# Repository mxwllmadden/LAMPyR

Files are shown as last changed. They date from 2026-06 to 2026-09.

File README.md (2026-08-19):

# LAMPyR

LAMPyR is a Python framework for running and managing behavioral experiment rigs. It provides a command-line interface and a Textual terminal UI for configuring rig hardware/interfaces, tracking mouse performance, running automated behavioral training paradigms, and has a notification manager to alert experimenters to session completion.

## Features

- Click-based `lampyr` command-line interface
- Textual TUI launcher (`lampyr go`)
- Rig configuration and calibration helpers
- Mouse creation, retirement, paradigm assignment, and run history
- Session and mouse data persistence using JSON/HDF5-backed utilities
- Optional Pushover notifications
- Hardware build files in `hardware/`
- Arduino firmware sketches for Bandit rig variants in `firmware/`

## Documentation

- [CLI command reference](docs/cli_commands.md)
- [GUI workflow](docs/gui_workflow.md)
- [Application architecture and segment inheritance](docs/app_architecture_and_segments.md)
- [Training management](docs/training_management.md)

## Requirements

- Windows is recommended for hardware/TUI operation; some rig and touch-overlay features are Windows-specific.
- Linux is supported for CLI operation with a Linux compatible TUI planned soon.
- Conda or Miniforge/Miniconda
- Python 3.10 or newer; the provided Conda environment uses Python 3.12
- Git, if installing directly from GitHub
- Arduino drivers/firmware as required by your rig hardware

## Installation

### Recommended: Conda environment from this repository

From the repository root:

```bat
conda env create -f lampyr.yaml
conda activate lampyr
pip install .
```

Verify the install:

```bat
lampyr --help
lampyr info
```

### Developer install

Use an editable install if you plan to modify the source code:

```bat
conda env create -f lampyr.yaml
conda activate lampyr
pip install -e .
```

### Install directly from GitHub

```bat
conda create -n lampyr python=3.12 -y
conda activate lampyr
conda install -c conda-forge git -y
pip install "git+https://github.com/HudaLaboratory/LAMPyR.git@main"
```

### Optional video support

If you install without the provided Conda environment and need OpenCV/video support:

```bat
pip install "lampyr[video]"
```

For a local checkout, use:

```bat
pip install ".[video]"
```

## Windows setup scripts

This repository includes batch files for convenience:

- `lampyr_setup.bat` - installs/refreshes a LAMPyR Conda environment from the GitHub `main` branch.
- `lampyr_update.bat` - updates dependencies and reinstalls LAMPyR from GitHub.

Review these scripts before running them, especially on machines with existing Conda environments.

## Configuration

LAMPyR stores user configuration under:

```text
%LOCALAPPDATA%\lampyr\config.json
```

Default settings include a shared mouse data directory:

```text
N:/SHARED/Maxwell_LAMPyR_MouseData
```

On first run, configure the installation (every other command requires this):

```bat
lampyr configure
```

Then inspect and configure the installation:

```bat
lampyr info
lampyr rig info
lampyr rig configure
lampyr rig calibrate
```

To reset configuration to defaults:

```bat
lampyr reset
```

> Note: `lampyr reset` is currently non-functional (`reset_to_default()` is
> not yet implemented) and will raise an error.

## Basic usage

Launch the terminal UI:

```bat
lampyr go
```

List available behaviors:

```bat
lampyr list
```

Create and inspect a mouse:

```bat
lampyr mouse create MOUSE_ID
lampyr mouse info MOUSE_ID
lampyr mouse list
```

Set or inspect a mouse paradigm/stage:

```bat
lampyr mouse paradigm MOUSE_ID
lampyr mouse paradigm MOUSE_ID BanditParadigm3
lampyr mouse paradigm MOUSE_ID BanditParadigm3 --stage Stage1AnyWheel
```

Run a behavior for a mouse:

```bat
lampyr mouse run MOUSE_ID
lampyr mouse run MOUSE_ID BEHAVIOR_NAME
```

Run a behavior directly:

```bat
lampyr run BEHAVIOR_NAME
```

Common stop-condition options include:

```text
--duration_limit / -dl
--trial_limit / -tl
--reward_limit / -rl
--merit_limit / -ml
--demerit_limit / -dml
```

Use command help for the full option list:

```bat
lampyr mouse run --help
lampyr run --help
```

## Notifications

LAMPyR supports Pushover notifications. Configure an app token and users with:

```bat
lampyr user set-token TOKEN
lampyr user create USERNAME --pushover_user_key USER_KEY
lampyr user list
lampyr user ping --user USERNAME --message "LAMPyR notification test"
```

## Hardware build files

Hardware files for building LAMPyR rigs are in `hardware/`:

- `hardware/BOM_Hardware.xlsx` - hardware bill of materials.
- `hardware/3d models/` - printable 3D model files.
- `hardware/Custom PCB shield/` - PCB shield fabrication files, BOM, designators, and pick-and-place positions.
- `hardware/eMachineShop design files/` - eMachineShop design files for machined components.

## Firmware

Arduino sketches for supported rig variants are in `firmware/`. Flash the sketch matching your rig hardware before attempting to run sessions.

## Project layout

```text
lampyr/                 Python package
lampyr/interfaces/      CLI (click_cli) and Textual TUI (textual_tui) entry points
lampyr/managers/        Data, mouse, rig, plugin, and notification managers
lampyr/rigs/            Hardware rig abstractions and Bandit rig components
lampyr/segments/        Segment, task, trial, stage, and paradigm abstractions
lampyr/behaviors/       Behavior implementations
lampyr/analysis/        Data analysis helpers
lampyr/main.py, config.py, primatives.py, files.py, actions.py, math.py, version.py   Core runtime modules
hardware/               Hardware BOM, 3D models, PCB shield files, and machining files
firmware/               Arduino firmware sketches
lampyr.yaml             Conda environment definition
```

## LLM Assisted Coding Disclosure

Some code in this repository was generated or written with the assistance of an LLM coding agent. ALL code has been tested, read, and verified by Maxwell Madden.

Specifically, LLMs were used to generate the lampyr.analysis.colony query based session retrieval code and the 'lampyr go' GUI. All other code was manually written.

## License

This project is distributed under the MIT License.

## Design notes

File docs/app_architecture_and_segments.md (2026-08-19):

# LAMPyR app architecture and segment inheritance

LAMPyR is a Python framework for running behavioral rig sessions. The central idea is that an experiment is represented as a tree of **segments**. Segments inherit context from their parents, record data while they run, and dump their state into a session at the end.

This document describes the application structure and how to create new tasks by inheriting from segment objects.

## High-level architecture

Core package areas:

- `lampyr/main.py` — top-level `Lampyr` orchestrator.
- `lampyr/config.py` — JSON-backed user configuration.
- `lampyr/primatives.py` — `Mouse`, `Session`, and unique ID primitives.
- `lampyr/managers/` — data, mouse, rig, plugin, and notification managers.
- `lampyr/rigs/` — hardware rig abstractions and concrete Bandit rig components.
- `lampyr/segments/` — segment base classes for trials, tasks, stages, and paradigms.
- `lampyr/behaviors/` — concrete behavior implementations.
- `lampyr/interfaces/click_cli/` — Click CLI.
- `lampyr/interfaces/textual_tui/` — Textual GUI/TUI.
- `lampyr/analysis/` — colony, records, traces, dataset, segments, time, and longtidy helpers.

## `Lampyr`: the application object

`Lampyr` is the top-level runtime object. Constructing it creates:

- `config`: a `Config` loaded from `%LOCALAPPDATA%/lampyr/config.json`.
- `datamanager`: a `DataHandler` for mouse/session save/load and backups.
- `rigmanager`: a `RigManager` for connecting, disconnecting, and calibrating the physical rig.
- `mousemanager`: a `MouseManager` for creating, loading, saving, and retiring mice.
- `notificationmanager`: a `NotificationManager` for Pushover notifications.
- `behaviors`: a registry mapping segment class names to imported `Segment` subclasses.
- `paradigms`: an initially empty dict intended for paradigm classes/user population.

The important runtime method is:

```python
lampyr.run(segment_name: str, **kwargs)
```

It:

1. Validates that `segment_name` exists in the behavior registry.
2. Requires an active rig.
3. Creates a new `Session`, injecting the active mouse ID if available.
4. Instantiates the selected segment with `lampyr=self` and `_verbose=True`.
5. Calls `segment.run()`.
6. Prints the session summary.
7. Evaluates stop conditions.
8. Sends a completion notification.

`Lampyr.close()` disconnects the rig, saves the session, saves the active mouse, and updates local mouse backups.

## Data model

### Mouse

`Mouse` represents one experimental subject. Key fields:

- `mouseid`
- `retired`
- `mouse_behav_param_overrides`
- `paradigm`
- `properties`
- `history`

`properties` is where paradigm-specific persistent state lives. A paradigm with slug `BanditParadigm`, for example, stores current stage and shaping data under `mouse.properties['BanditParadigm']`.

`mouse_behav_param_overrides` supports per-mouse parameter overrides. Keys may be:

- `'all'`
- a segment `slug`
- one of a segment's inherited `tags`

Values are dictionaries of `{attribute_name: override_value}`. Overrides only apply to attributes that already exist on the segment.

### Session

`Session` stores all counters, limits, metadata, segment records, events, rig data, and extended data references for one run.

Important counters include:

- `merit`, `demerit`
- `trial`
- `rewards`, `reward_amount`
- `abstention`
- `participation`
- `serial_abstention`
- `duration`

Each counter has optional `_min` and `_limit` companions. `Session.evaluatestopconditions()` returns a list of stop reasons when limits are reached. `Session.lock()` finalizes the session and makes it immutable.

## Segment hierarchy

The segment classes are in `lampyr/segments/`.

```text
Segment
├── BehaviorSegment
│   ├── Task
│   └── Trial
└── ParadigmSegment
    ├── Stage
    └── Paradigm
```

### `Segment`

`Segment` is the abstract base for all executable experiment units.

Subclasses must implement:

```python
def execute(self):
    ...
```

`Segment.run()` wraps `execute()` with common behavior:

1. Prevents running the same segment twice.
2. Records `starttime`.
3. Calls `execute()`.
4. Records `endtime`.
5. Freezes the segment.
6. Calls `dump()` even if execution exits by exception.

`Segment.dump()` serializes public segment state into `session.segments`. If the segment is the root segment (`rank == 0`), it also stops rig acquisition, dumps rig data into the session, and locks the session.

### Parent inheritance

Segments form a tree. Child segments should be instantiated with `parent=self`:

```python
trial = MyTrial(parent=self)
trial.run()
```

A child automatically inherits common runtime context from its parent:

- `lampyr`
- `rig`
- `mouse`
- `session`
- `_output_func`
- `_verbose`

The child rank becomes `parent.rank + 1`. When a non-root child dumps, its `uniqueid` is appended to `parent.subdata`, giving the session a navigable tree.

If a segment has no parent but has a `lampyr` object, it inherits context directly from `lampyr`.

### `BehaviorSegment`

`BehaviorSegment` adds behavior-specific support:

- inherited/combinable `tags`
- `reports`
- `event_definitions`
- `event_records`
- registered event callbacks
- `stop_reasons`
- mouse parameter overrides
- counter logging helpers

Common methods:

```python
self.register_event(name, callback=..., description=...)
self.trigger_event(name, *args, **kwargs)
self.create_report(key, value)
self.log_merit()
self.log_demerit()
self.log_abstention()
self.log_participation()
self.log_reward(amount)
self.log_trial()
self.finish()
self.notify(message)
```

### `Task`

`Task` is for trialless behaviors or behaviors that repeatedly create trials.

Subclasses implement:

```python
def setup(self):
    ...

def loop(self):
    ...
```

`Task.execute()` calls `setup()` once and then repeatedly calls `loop()` until session stop conditions are met.

### `Trial`

`Trial` is for one discrete trial.

Subclasses implement:

```python
def setup(self):
    ...

def perform(self):
    ...
```

`Trial.execute()` calls `setup()`, then `perform()`, then logs one trial and marks itself finished.

Useful helpers:

```python
self.wait(seconds)
self.waitfor(condition, fallback_value=None, timeout=None, poll_interval=0.05)
```

`waitfor()` polls a condition until it returns a truthy value or a timeout
occurs. It also accepts `while_waiting` (a callback invoked periodically while
waiting) and `while_waiting_interval` (seconds between those callbacks).

## Creating a new task

The usual pattern is:

1. Create a `Trial` subclass for one unit of behavior.
2. Create a `Task` subclass that runs that trial repeatedly.
3. Import the module before the `Lampyr` registry is built.
4. Run the task by class name from the CLI or GUI.

### Example: one trial plus one task

```python
# lampyr/behaviors/my_behavior.py

from dataclasses import dataclass
from lampyr.segments import Trial, Task, BehaviorSegment

def reward_callback(segment: BehaviorSegment):
    segment.rig.reward.give()
    segment.log_reward(0.005)

@dataclass
class MyChoiceTrial(Trial):
    slug: str = "MyChoiceTrial"
    response_window_s: float = 3.0
    response_threshold_deg: float = 15.0

    def setup(self):
        self.register_event(
            "reward",
            callback=reward_callback,
            description="Deliver one calibrated water reward",
        )
        self.register_event(
            "response",
            description="Wheel movement crossed response threshold",
        )

    def perform(self):
        self.rig.wheel.home()
        response = self.waitfor(
            condition=lambda: abs(self.rig.wheel.angle()) > self.response_threshold_deg,
            fallback_value=False,
            timeout=self.response_window_s,
            poll_interval=0.01,
        )

        if response:
            self.trigger_event("response")
            self.trigger_event("reward")
            self.create_report("responded", True)
            self.log_merit()
        else:
            self.create_report("responded", False)
            self.log_abstention()

@dataclass
class MyChoiceTask(Task):
    slug: str = "MyChoice"

    def setup(self):
        self.tags.append("choice")

    def loop(self):
        trial = MyChoiceTrial(parent=self)
        trial.run()
```

Run it after it is imported:

```bat
lampyr mouse run 014-003 MyChoiceTask --duration_limit 30 --reward_limit 100
```

### Prefer `field(default_factory=...)` for mutable defaults

Because segments are dataclasses, mutable defaults must use `field(default_factory=...)`.

Good:

```python
from dataclasses import dataclass, field
from lampyr.segments import Trial

@dataclass
class MyTrial(Trial):
    reward_probs: dict = field(default_factory=lambda: {"Left": 80, "Right": 20})
```

Avoid:

```python
reward_probs: dict = {"Left": 80, "Right": 20}  # do not do this
```

### Running one trial per loop with `TrialToTask`

For simple behaviors, `TrialToTask` can generate a task wrapper automatically.

```python
from dataclasses import dataclass
from lampyr.segments import Trial, TrialToTask

@TrialToTask
@dataclass
class LaserPulseTrial(Trial):
    slug: str = "LaserPulse"
    pulse_s: float = 2.0

    def setup(self):
        pass

    def perform(self):
        self.rig.laser.begin()
        self.wait(self.pulse_s)
        self.rig.laser.stop()
```

This creates a task class named `LaserPulseTrialTask` that runs `LaserPulseTrial` once per task loop.

## Inheriting from existing task/trial classes

You can create new behavior variants by subclassing an existing concrete class and overriding dataclass fields or selected methods.

Example:

```python
from dataclasses import dataclass
from lampyr.behaviors.bandit import BanditTask

@dataclass
class HighRewardLeftBandit(BanditTask):
    slug: str = "HighRewardLeft"
    target_mode: str = "Left"
    reward_prob_target: int = 90
    reward_prob_offtarget: int = 10
    taskblocks_enabled: bool = False
```

Because `HighRewardLeftBandit` inherits from `BanditTask`, it keeps the Bandit task loop but changes the parameters. It is discoverable by class name once its module is imported.

For more substantial changes, override `setup()` or `loop()` and call `super()` where appropriate:

```python
@dataclass
class MyBanditVariant(BanditTask):
    slug: str = "MyBanditVariant"

    def setup(self):
        super().setup()
        self.log_notice("Using custom setup")

    def loop(self):
        # custom pre-trial logic
        super().loop()
        # custom post-trial logic
```

## Event and report design

Use events for timestamped occurrences and reports for trial/segment outcomes.

Events:

```python
self.register_event("cue", description="Cue onset")
t_cue = self.trigger_event("cue")
```

Events are recorded in the segment and appended to `session.eventlist`.

Reports:

```python
self.create_report("response", "Left")
self.create_report("rewarded", True)
```

Reports are stored inside the dumped segment data and are useful for analysis and stage shaping.

## Session counter design

Use counter helpers so stop conditions and summaries work correctly:

- `log_trial()` increments `session.trial`.
- `log_reward(amount)` increments reward count and reward amount.
- `log_merit()` increments merit and participation.
- `log_demerit()` increments demerit and participation.
- `log_abstention()` increments abstention and serial abstention.
- `log_participation()` increments participation and resets serial abstention.

Do not update counters directly unless you have a specific reason.

## Creating a paradigm and stages

Use `Paradigm` when a mouse should progress through stages across sessions.

A `Stage` implements:

```python
def define_sessionparams(self):
    ...

def define_task(self, stage_data):
    ...

def session_summary(self):
    ...

def define_shaping(self, stage_data):
    ...
```

A `Paradigm` supplies `stagelist` and progression logic:

```python
from dataclasses import dataclass
from lampyr.segments import Stage, Paradigm

@dataclass
class StageA(Stage):
    slug: str = "StageA"

    def define_sessionparams(self):
        self.set_sessionparam("duration_limit", 30)
        self.set_sessionparam("reward_limit", 100)

    def define_task(self, stage_data):
        task = MyChoiceTask(parent=self)
        task.run()

    def session_summary(self):
        self.log_notice(str(self.session))

    def define_shaping(self, stage_data):
        stage_data["last_merit"] = self.session.merit

@dataclass
class MyParadigm(Paradigm):
    slug: str = "MyParadigm"
    stagelist: tuple = (StageA,)

    def define_progression(self, current_stage, stage_data):
        pass
```

Assign and run it:

```bat
lampyr mouse paradigm 014-003 MyParadigm --stage StageA
lampyr mouse run 014-003
```

Important paradigm details:

- `Paradigm` must run as the root segment.
- It requires a `Lampyr` instance and an active mouse.
- It stores persistent data in `mouse.properties[paradigm.slug]`.
- It selects the current stage from that persistent data.
- Stage `set_sessionparam()` respects explicit user overrides by warning instead of overwriting existing session values.

## Making new behaviors discoverable

`Lampyr.__init__()` builds its registry from already-imported subclasses:

```python
self.behaviors = {c.__name__: c for c in Segment.get_children()}
```

Therefore, defining a class is not enough; the module containing it must be imported before the `Lampyr` object is created.

Current CLI behavior imports include:

```python
from lampyr.behaviors import bandit
from lampyr.behaviors import test
```

Common options for adding a new behavior module:

1. Add the module under `lampyr/behaviors/`.
2. Import it from `lampyr/interfaces/click_cli/app.py`, or from `lampyr/behaviors/__init__.py` and ensure that package import happens before registry creation.
3. Run `lampyr list` to verify the class appears.

Example import line:

```python
from lampyr.behaviors import my_behavior
```

If the class does not appear in `lampyr list`, it has not been imported early enough.

## Hardware access from segments

Segments that inherit rig context can call rig components. For the Bandit rig, commonly used components include:

- `self.rig.wheel.home()`
- `self.rig.wheel.angle()`
- `self.rig.wheel.movement_total_since(t)`
- `self.rig.licks.since(t)`
- `self.rig.play.begintrialtone()`
- `self.rig.play.responsetone()`
- `self.rig.play.punishtone()`
- `self.rig.reward.give()`
- `self.rig.reward.setsize(size)`
- `self.rig.wheellock.lock()`
- `self.rig.wheellock.unlock()`
- `self.rig.wheellock.to_angle(angle)`
- `self.rig.laser.begin()`
- `self.rig.laser.stop()`
- `self.rig.laser.rampdown(ramp_ms)`
- `self.rig.initialize_mousecam()`

Always design segment code so the root segment can finish and dump cleanly. Avoid swallowing `KeyboardInterrupt` unless you re-raise it after cleanup.

## Persistence and analysis implications

Every segment dump includes:

- identifiers (`name`, `slug`, `uniqueid`)
- timing (`starttime`, `endtime`)
- tree structure (`rank`, `subdata`, `parent` representation)
- records/logs
- behavior reports/events
- inherited tags and event definitions
- `segment_type`, a list of parent segment class names

The `Session.search()` helper can later retrieve segments by type, slug, report checks, or custom filters.

Good task design makes analysis easier:

- Give classes and slugs stable names.
- Store outcome variables in `reports`.
- Use events for timestamps.
- Use counter helpers for global session metrics.
- Keep mutable task state in clearly named dataclass fields.

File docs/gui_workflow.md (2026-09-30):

# LAMPyR GUI workflow

LAMPyR's GUI is a Textual terminal user interface launched by:

```bat
lampyr go
```

The GUI is implemented in `lampyr/interfaces/textual_tui/app.py`. It is designed for touch-first operation on rig computers while still supporting mouse/keyboard interaction.

## Startup behavior

When `lampyr go` starts:

1. A `LampyrApp` Textual application is created.
2. A `Lampyr` object is created with custom input/output handlers so blocking prompts and log output can be routed through the TUI.
3. The main screen is pushed.
4. A heartbeat timer is scheduled every 20 minutes.

On Windows only, the CLI wrapper also:

- toggles fullscreen with F11;
- disables Quick Edit mode in the terminal;
- enables terminal mouse input;
- starts an invisible touch-to-mouse bridge unless `--notouchoverlay` is supplied.

```bat
lampyr go --notouchoverlay
```

Use `--notouchoverlay` if the transparent Windows touch bridge interferes with local input handling.

## Main screen

The main screen shows the configured rig name as ASCII art and these buttons:

1. `RUN`
2. `ADVANCED`
3. `CALIBRATE`
4. `AUTOMATED TASK` when automated tasks are enabled
5. `QUIT`

The rig name comes from `config['rig.name']`. If no rig name is configured, the title falls back to `Lampyr`. Automated tasks can be enabled during initial `lampyr configure` setup or later through setting 5 in the configuration menu.

## RUN workflow: normal mouse/paradigm run

Tap `RUN` for the default day-to-day workflow.

1. The GUI opens an ID-entry numpad.
2. Enter the mouse ID and confirm.
3. LAMPyR attempts to load the mouse.
4. If the mouse has an assigned `mouse.paradigm`, the GUI starts that behavior directly.
5. If the mouse does not have an assigned paradigm, the GUI opens the behavior selection screen instead.

Typical use:

```text
RUN → Enter Mouse ID → Run assigned paradigm
```

If the mouse ID cannot be loaded, the app displays an error notification and stays in the GUI.

## ADVANCED workflow: choose a task manually

Tap `ADVANCED` when you want to run a specific task instead of the mouse's assigned paradigm.

1. The GUI opens an ID-entry numpad.
2. Enter the mouse ID and confirm.
3. LAMPyR loads the mouse.
4. The behavior selection screen appears.
5. Pick a task.
6. The task-parameter screen appears.
7. Edit session limits if needed.
8. Tap `RUN`.

Typical use:

```text
ADVANCED → Enter Mouse ID → Select Task → Configure limits → RUN
```

The behavior selector lists imported subclasses of `Task` and excludes the abstract base `Task` itself. It does not list stages or paradigms in this advanced task-selection flow.

## Task parameter screen

Before an advanced task run, the GUI shows editable session parameters. Defaults are:

- `reward_limit = 200`
- `duration_limit = 60`
- `serial_abstention_limit = 15`

Editable parameters:

- Reward Limit
- Duration (min)
- Trial Limit
- Merit Limit
- Demerit Limit
- Participation Limit
- Abstention Limit
- Serial Abstention Limit

Tap a parameter to open the integer numpad. Enter a value and confirm. Entering `-` clears that parameter so it will not be passed as a session override.

When `RUN` is tapped, these values are passed as keyword arguments to `Lampyr.run()` and become `Session` stop conditions.

## Automated task workflow

When automated tasks are enabled, tap `AUTOMATED TASK` to configure the rig's single recurring schedule.

1. Select a concrete `Task` subclass. No mouse ID is requested.
2. Set the start and end of the daily local-time window using strict 24-hour `HH:MM` values.
3. Tap `SAVE` to persist the complete schedule and reset its previous run marker.

The selector's `None` button clears the configured task. It appears only in scheduling mode. `RETURN TO MAIN` exits without selecting a task, while `BACK` on the time screen returns to task selection without saving.

Both ordinary ranges such as `09:00`–`10:00` and overnight ranges such as `22:00`–`02:00` are supported. An overnight window is associated with the date on which it starts.

## Run screen

The run screen is a black log-output screen with one large action button.

During a session, the button is:

```text
ABORT
```

The run thread performs the following steps:

1. Load the mouse.
2. Check rig configuration.
3. Check calibration age.
4. Connect to the rig.
5. Start the selected behavior/paradigm.
6. Stream log output to the screen.

The rig checks mirror the CLI run checks:

- `rig.configured` must be truthy.
- `rig.calibrated` must be newer than five days.

If either check fails, the run screen reports the error and does not start a session.

### Aborting a run

Tap `ABORT` while a session is running to force a `KeyboardInterrupt` into the worker thread. The app also sets an internal `_user_aborted` flag on the `Lampyr` instance so the final stop reasons include user intervention.

After a session ends, the action button changes to a return button:

- `RETURN TO MAIN` for a clean finish.
- `RETURN (session ended with error)` for an error finish.

Returning cancels the post-session animal-left timer. Returning from a manual run also invokes the heartbeat immediately.

### Scheduled run screen

A due automated task opens a scheduled run screen that reuses the normal session log and `ABORT` control. It creates `AUTOMOUSE` if necessary and explicitly loads that sentinel before every scheduled run, ensuring a previously loaded real mouse cannot receive the automated session.

Scheduled runs do not start the post-session animal-left timer. They automatically return to the main menu after success, abort, or error, and invoke the heartbeat after returning.

### Post-session animal-left alert

When a run finishes, the GUI starts a 30-minute timer. If the user has not returned from the run screen by then, the app sends an urgent notification warning that a mouse may have been left in the rig.

Recipients are active users and supervisors from the shared notification user configuration.

## Calibration workflow

Tap `CALIBRATE` to begin calibration.

1. A yellow confirmation screen appears.
2. Tap `BEGIN CALIBRATION` to proceed, or `CANCEL` to return.
3. The calibration screen opens a log panel.
4. LAMPyR connects to the rig if needed.
5. The calibration routine prompts for weights using the GUI numpad.
6. When calibration completes, `RETURN TO MAIN` appears.

Calibration is the same routine used by:

```bat
lampyr rig calibrate
```

It updates the stored sipper calibration and calibration timestamp on success.

## Heartbeat, calibration, and automated execution

The heartbeat runs at startup, every 20 minutes, and whenever a manual or scheduled run returns to the main menu.

Calibration has priority. If calibration is older than five days and no calibration/run screen is active, the heartbeat pushes the calibration confirmation screen and does not launch automated work.

When calibration is current, the heartbeat launches the configured automated task only when:

- automated tasks are enabled;
- the task name resolves to a concrete imported `Task` subclass;
- both configured times are valid;
- local system time is inside the configured range;
- the app is idle on the main screen; and
- the logical daily window has not already been attempted.

The window identifier is persisted immediately before launch. Consequently, a task is attempted at most once per window even if startup fails. Because periodic checks are 20 minutes apart, use a window wider than 20 minutes if it must be observed reliably.

The heartbeat also touches `heartbeat.file` in the shared mice directory when no session is running. If that file operation fails, the GUI displays an error notification.

## Numpad modal

The GUI uses a touch-friendly numpad modal for:

- mouse IDs;
- integer session parameters;
- floating-point calibration weights; and
- automated-task start and end times.

Modes:

- `id`: digits plus `-`; requires a non-empty string.
- `int`: digits plus optional leading `-`; validates as an integer. A single `-` is used in the task parameter screen to clear a parameter.
- `float`: digits plus decimal point; validates as a float.
- `time`: digits plus `:`; requires a canonical 24-hour `HH:MM` value from `00:00` through `23:59`.

All entries use a confirmation step before submission.

## Output routing

The TUI routes normal LAMPyR text output into screen-specific RichLog widgets.

- Calibration output goes to the calibration log.
- Session output goes to the run log.
- Other screens suppress standard output unless they explicitly install an output handler.

This works through `LampyrApp.set_output()`, which updates the top-level `Lampyr` object and all managers (`rigmanager`, `mousemanager`, `datamanager`, and `notificationmanager`).

## Quitting

Tap `QUIT` on the main screen to exit the app.

Avoid closing the terminal during an active session unless necessary. The run screen's `ABORT` button gives LAMPyR a better chance to record stop reasons, dump segment data, stop rig acquisition, save the session, save the mouse, and send notifications.

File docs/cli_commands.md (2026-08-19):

# LAMPyR CLI command reference

This document describes the Click command-line interface defined in `lampyr/interfaces/click_cli/app.py`. The installed console script is `lampyr`; on Windows, commands are often shown as `LAMPyR` and are equivalent in normal use.

Most commands create a `Lampyr` application object, load configuration from `%LOCALAPPDATA%/lampyr/config.json`, and close cleanly when the command exits. Commands that run behavior connect to the configured rig, create a session, run a segment by class name, save session/mouse data, and send completion notifications when configured.

## Global form

```bat
lampyr [OPTIONS] COMMAND [ARGS]...
```

Top-level commands:

- `lampyr configure`
- `lampyr info`
- `lampyr list`
- `lampyr reset`
- `lampyr developer`
- `lampyr go`
- `lampyr run BEHAVIOR [SESSION OPTIONS]`
- `lampyr rig ...`
- `lampyr mouse ...`
- `lampyr user ...`

Use Click's built-in help for command-specific help:

```bat
lampyr --help
lampyr mouse run --help
lampyr user ping --help
```

## Session stop-condition options

The direct run commands (`lampyr run` and `lampyr mouse run`) accept the same set of optional session parameters. They are forwarded to `lampyr.primatives.Session` and evaluated during task execution.

| Option | Short | Type | Meaning |
|---|---:|---|---|
| `--merit_limit` | `-ml` | int | Stop when merit count is at least this value. |
| `--merit_min` | `-mm` | int | Do not stop for non-reward limits until merit count reaches this value. |
| `--demerit_limit` | `-dml` | int | Stop when demerit count is at least this value. |
| `--demerit_min` | `-dmm` | int | Do not stop for non-reward limits until demerit count reaches this value. |
| `--duration_limit` | `-dl` | int | Stop after this many minutes. |
| `--duration_min` | `-dm` | int | Do not stop for non-reward limits until this many minutes have elapsed. |
| `--trial_limit` | `-tl` | int | Stop when trial count is at least this value. |
| `--trial_min` | `-tm` | int | Do not stop for non-reward limits until trial count reaches this value. |
| `--reward_limit` | `-rl` | int | Stop when reward count is at least this value. Reward limits are privileged and are checked before minimum gates. |
| `--reward_min` | `-rm` | int | Do not stop for non-reward limits until reward count reaches this value. |
| `--abstention_limit` | `-al` | int | Stop when abstention count is at least this value. |
| `--abstention_min` | `-am` | int | Do not stop for non-reward limits until abstention count reaches this value. |
| `--participation_limit` | `-pl` | int | Stop when participation count is at least this value. |
| `--participation_min` | `-pm` | int | Do not stop for non-reward limits until participation count reaches this value. |
| `--serial_abstention_limit` | `-sal` | int | Stop when consecutive abstention count is at least this value. |
| `--serial_abstention_min` | `-sam` | int | Do not stop for non-reward limits until consecutive abstention count reaches this value. |

Notes:

- Limits with value `None` are ignored.
- Reward count and reward amount limits are intentionally privileged in the session evaluator to avoid accidental over-delivery.
- Minimums gate later limit checks: for example, `--duration_min 10 --trial_limit 20` prevents the trial limit from ending the session until 10 minutes have elapsed.

## Top-level commands

### `lampyr configure`

First-run setup. Every other command refuses to run until `lampyr.configured`
is true, so this must be run once before anything else.

```bat
lampyr configure
```

It interactively prompts for:

- The session/mouse data path (`lampyr.mice_directory`).
- Whether to enable the save/load failsafe (`y`/`n`).
- Whether to enable local mouse file backups (`y`/`n`).
- Whether to enable plugins and, if so, the plugin folder path.

On completion it sets `lampyr.configured` to `True`.

### `lampyr info`

Prints the LAMPyR version banner and the full loaded configuration.

```bat
lampyr info
```

### `lampyr list`

Lists all currently imported behavior segment subclasses grouped as paradigms, stages, tasks, and trials.

```bat
lampyr list
```

The CLI imports `lampyr.behaviors.bandit` and `lampyr.behaviors.test`, so classes from those modules are normally present. New behavior modules must be imported before the `Lampyr` object builds its subclass registry.

### `lampyr reset`

Prompts for confirmation (`YES`) before resetting configuration to defaults.

```bat
lampyr reset
```

> **Note:** This command is currently non-functional. It calls
> `config.reset_to_default()`, which is not yet implemented, so it raises an
> `AttributeError` after confirmation.

### `lampyr developer`

Developer shortcut guarded by a password prompt.

```bat
lampyr developer
```

If the prompt receives the expected password, it sets:

- `rig.calibrated` to a far-future value
- `rig.name` to `Photuris`
- `rig.configured` to `True`

This is intended for development/testing, not normal rig operation.

### `lampyr go`

Launches the Textual terminal UI.

```bat
lampyr go
lampyr go --notouchoverlay
```

Options:

- `--notouchoverlay`: disables the Windows touchscreen-to-mouse overlay bridge.

On Windows, `go` toggles the terminal fullscreen with F11, disables Quick Edit mode, enables mouse input, and starts a transparent touch bridge unless disabled.

### `lampyr run BEHAVIOR`

Runs a behavior by class name without explicitly loading a mouse. The default active mouse is `UNKNOWN_MOUSE` unless code has loaded a mouse before the run.

```bat
lampyr run RewardedHabituationTask -dl 60 -rl 200
lampyr run BanditTask --trial_limit 100 --duration_limit 45
```

Before running, LAMPyR checks that:

1. `rig.configured` is truthy.
2. `rig.calibrated` is newer than five days.
3. The rig can connect.

If checks pass, `Lampyr.run()` creates a session and instantiates the named behavior from the segment subclass registry.

## Rig commands

### `lampyr rig info`

Prints the `rig` section of the current config.

```bat
lampyr rig info
```

### `lampyr rig configure`

Prompts for a rig name and marks the rig configured.

```bat
lampyr rig configure
```

Current stored values updated:

- `rig.name`
- `rig.configured = 1`

### `lampyr rig calibrate`

Runs the interactive sipper calibration routine.

```bat
lampyr rig calibrate
```

Workflow:

1. Connects to the rig if it is not already connected.
2. Tests three dispenser sizes around the current estimate.
3. Prompts for scale weights before/after reward trains.
4. Fits a line and estimates the size for ~5 µl/reward.
5. Validates the estimate.
6. Saves `rig.sipper_calib` and updates `rig.calibrated` when successful.

Entering `0` at a weight prompt restarts the calibration cycle.

## Mouse commands

### `lampyr mouse create MOUSEID`

Creates a mouse directory and mouse metadata file.

```bat
lampyr mouse create 014-003
lampyr mouse create 014-003 --force
```

Arguments/options:

- `MOUSEID`: required mouse identifier.
- `--force`: overwrite/update even if an existing mouse is found.

Without `--force`, creation aborts if the mouse already exists.

> **Note:** `--paradigm`/`-p` is accepted but currently has no effect — it
> checks the `lampyr.paradigms` registry, which is empty unless populated by
> code. Create the mouse first, then assign the paradigm with
> `lampyr mouse paradigm`.

### `lampyr mouse retire MOUSEID`

Marks a mouse as retired and saves it.

```bat
lampyr mouse retire 014-003
```

Retired mice are hidden from `mouse list` unless `-all` is used.

### `lampyr mouse list`

Prints a table of known mice.

```bat
lampyr mouse list
lampyr mouse list -recent
lampyr mouse list -all
```

Options:

- `-recent`: only show mice with a last session less than 12 hours ago.
- `-all`: include retired mice.

Columns include mouse ID, assigned paradigm, current stage, time since last session, last merit count, and last reward count.

### `lampyr mouse info MOUSEID`

Loads and prints a mouse object.

```bat
lampyr mouse info 014-003
```

### `lampyr mouse paradigm MOUSEID [PARADIGM_NAME]`

Inspect or change a mouse's assigned paradigm and current stage.

Inspect current paradigm data:

```bat
lampyr mouse paradigm 014-003
```

Set a paradigm:

```bat
lampyr mouse paradigm 014-003 BanditParadigm
```

Set a paradigm and stage:

```bat
lampyr mouse paradigm 014-003 BanditParadigm3 --stage Stage1AnyWheel
lampyr mouse paradigm 014-003 BanditParadigm3 -s Stage1AnyWheel
```

Set only the current stage for the already-assigned paradigm:

```bat
lampyr mouse paradigm 014-003 --stage Stage2Correction
```

Stage names are the paradigm's stage `slug` values (e.g. `Stage0Hab`,
`Stage1AnyWheel`, `Stage2Correction`, `Stage3Return`, `Stage5BanditTraining`,
`Stage6Bandit`) and are validated against the paradigm's `stagelist`.

### `lampyr mouse run MOUSEID [BEHAVIOR]`

Loads a mouse, starts the rig, and runs a behavior.

```bat
lampyr mouse run 014-003
lampyr mouse run 014-003 BanditTask -dl 60 -rl 200 -sal 15
lampyr mouse run 014-003 BanditParadigm --duration_limit 60
```

Arguments/options:

- `MOUSEID`: required mouse identifier.
- `BEHAVIOR`: optional behavior/paradigm class name. If omitted, the mouse's assigned `mouse.paradigm` is used.
- Session options: all stop-condition options listed above.

Common failure cases:

- Unknown mouse ID: command prints an error and exits.
- Missing behavior when the mouse has no assigned paradigm: `Lampyr.run()` cannot find a valid segment.
- Rig unconfigured/uncalibrated: the command aborts before connecting.

## User/notification commands

Notification data is stored in the shared users config loaded by `NotificationManager`. Pushover delivery requires an app token and one or more user keys.

### `lampyr user set-token TOKEN`

Stores the shared Pushover app token.

```bat
lampyr user set-token APP_TOKEN
```

### `lampyr user create NAME`

Creates a notification user.

```bat
lampyr user create max --pushover_user_key USER_KEY
lampyr user create supervisor -super --pushover_user_key USER_KEY
```

Options:

- `--pushover_user_key`: Pushover user key.
- `-super`: mark the user as a supervisor. Supervisors are always active and cannot be deactivated.

### `lampyr user edit NAME`

Updates a notification user.

```bat
lampyr user edit max --pushover_user_key NEW_USER_KEY
lampyr user edit max --supervisor true
lampyr user edit max --supervisor false
```

Options:

- `--pushover_user_key`: replacement Pushover user key.
- `--supervisor BOOL`: set supervisor status.

### `lampyr user inspect NAME`

Prints one user's notification configuration.

```bat
lampyr user inspect max
```

### `lampyr user list`

Lists configured users and status tags.

```bat
lampyr user list
```

Tags:

- `[supervisor]`: always notified.
- `[active]`: normal active recipient.
- `[inactive]`: normal inactive recipient.

### `lampyr user activate NAME`

Marks a non-supervisor user active.

```bat
lampyr user activate max
```

### `lampyr user deactivate NAME`

Marks a non-supervisor user inactive.

```bat
lampyr user deactivate max
```

Supervisor users cannot be deactivated.

### `lampyr user ping`

Sends a test notification.

```bat
lampyr user ping
lampyr user ping --user max --message "test from rig"
lampyr user ping -u max -m "urgent test" --urgent
```

Options:

- `--user`, `-u`: send only to one user. If omitted, sends to every active/supervisor user.
- `--message`, `-m`: message body. Default is a generic test message.
- `--urgent`: send using Pushover emergency priority.

### `lampyr user remove NAME`

Deletes a notification user.

```bat
lampyr user remove max
```

## Typical CLI workflows

### First-time setup

```bat
lampyr configure
lampyr rig configure
lampyr rig calibrate
lampyr rig info
```

### Add a mouse and assign training

```bat
lampyr mouse create 014-003
lampyr mouse paradigm 014-003 BanditParadigm3
lampyr mouse paradigm 014-003 --stage Stage0Hab
lampyr mouse info 014-003
```

### Run a normal assigned paradigm

```bat
lampyr mouse run 014-003 -dl 60 -rl 200 -sal 15
```

### Run a specific task manually

```bat
lampyr mouse run 014-003 RewardedHabituationTask --duration_limit 30 --reward_limit 100
```

### Configure notifications

```bat
lampyr user set-token APP_TOKEN
lampyr user create max --pushover_user_key USER_KEY
lampyr user ping --user max --message "LAMPyR notification test"
```

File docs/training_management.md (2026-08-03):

# LAMPyR training management

This guide covers common ways to tweak mouse training without changing task source code. It focuses on the CLI workflows in `lampyr/interfaces/click_cli/app.py`, the runtime objects in `lampyr/main.py` and `lampyr/primatives.py`, and behavior parameter overrides applied by `BehaviorSegment._checkoverrides()`.

For the full command list, see [CLI command reference](cli_commands.md). For how paradigms, stages, tasks, trials, slugs, and tags fit together, see [Application architecture and segment inheritance](app_architecture_and_segments.md).

## Normal training progression: assign paradigm and stage

A mouse stores its normal training assignment in:

- `mouse.paradigm` — the behavior/paradigm class name to run by default.
- `mouse.properties` — persistent paradigm state, including the current stage.

Use `lampyr mouse paradigm` for normal progression edits.

Inspect current paradigm data:

```bat
lampyr mouse paradigm 014-003
lampyr mouse info 014-003
```

Assign or change the paradigm:

```bat
lampyr mouse paradigm 014-003 BanditParadigm3
```

Set the current stage for the already-assigned paradigm:

```bat
lampyr mouse paradigm 014-003 --stage Stage1AnyWheel
```

Assign paradigm and stage together:

```bat
lampyr mouse paradigm 014-003 BanditParadigm3 --stage Stage2Correction
```

Stage names are stage `slug` values, not necessarily the Python class names. For Bandit examples, stage slugs include values such as `Stage0Hab`, `Stage1AnyWheel`, `Stage2Correction`, `Stage3Return`, `Stage5BanditTraining`, and `Stage6Bandit` depending on the paradigm.

After changing an assignment, verify it before running:

```bat
lampyr mouse paradigm 014-003
lampyr mouse info 014-003
```

## Run a specific task manually

The default mouse run uses the assigned paradigm:

```bat
lampyr mouse run 014-003
```

To run a specific behavior instead of the assigned paradigm, provide the behavior class name:

```bat
lampyr mouse run 014-003 RewardedHabituationTask -dl 30 -rl 50
lampyr mouse run 014-003 BanditTask --duration_limit 45 --trial_limit 100
```

This loads the mouse, so mouse-specific overrides still apply. Supplying a behavior this way does **not** change `mouse.paradigm` or the mouse's assigned stage; it is a manual one-off run.

You can see available imported behaviors with:

```bat
lampyr list
```

## Adjust session stop conditions from the CLI

`lampyr mouse run` and `lampyr run` accept session stop-condition options that are forwarded to `Session`. Common options are:

| Option | Short | Meaning |
|---|---:|---|
| `--duration_limit` | `-dl` | Stop after this many minutes. |
| `--reward_limit` | `-rl` | Stop after this many delivered rewards. |
| `--trial_limit` | `-tl` | Stop after this many trials. |
| `--serial_abstention_limit` | `-sal` | Stop after this many consecutive abstentions. |
| `--merit_limit` | `-ml` | Stop after this many merits. |
| `--demerit_limit` | `-dml` | Stop after this many demerits. |
| `--abstention_limit` | `-al` | Stop after this many abstentions. |
| `--participation_limit` | `-pl` | Stop after this many participations. |

Most limits also have corresponding minimum options, such as `--duration_min`, `--trial_min`, and `--reward_min`. Minimums gate later stop checks; for example, a trial limit with a duration minimum will not stop the session until the duration minimum has elapsed.

Examples:

```bat
REM Short, low-reward session
lampyr mouse run 014-003 -dl 30 -rl 75

REM Stop early if the mouse has 15 consecutive abstentions
lampyr mouse run 014-003 BanditTask -dl 60 -sal 15

REM Fixed-length manual task by trial count
lampyr mouse run 014-003 BanditTask --trial_limit 120 --reward_limit 200
```

If a stage sets its own session parameters internally, CLI values take precedence when they are already set on the `Session`; the stage will log a warning that a stage parameter was overridden.

## Mouse behavior parameter overrides

Per-mouse behavior tweaks live in:

```python
mouse.mouse_behav_param_overrides
```

There is not currently a dedicated CLI command known for editing this field. Use a careful Python edit or direct mouse JSON edit.

Overrides are applied when each `BehaviorSegment` is created. In the built-in hierarchy this means tasks and trials, not paradigm/stage session parameters. The override value must target an attribute that already exists on that segment; misspelled or nonexistent attributes are ignored.

### Override key matching

`BehaviorSegment._checkoverrides()` checks keys in this order:

1. `all` — applies to every behavior segment.
2. The segment's `slug`, such as `BanditTask`, `BanditTrial`, `RewHab`, or a custom slug.
3. Each inherited tag in `segment.tags`, such as `experiment` when a task defines that tag.

If multiple matching overrides set the same attribute, later applications can replace earlier values.

Example structure:

```python
{
    "BanditTrial": {
        "responsewindow_s": 5,
        "responsethresholds_deg": {"Left": 10, "Right": 10}
    },
    "BanditTask": {
        "taskblocks_enabled": False,
        "reward_prob_target": 100,
        "reward_prob_offtarget": 0
    },
    "experiment": {
        "enable_wheel_lock": True
    }
}
```

### Edit overrides with Python

This is usually safer than hand-editing JSON:

```python
from lampyr import Lampyr

app = Lampyr()
try:
    app.mousemanager.load("014-003")
    mouse = app.mouse

    overrides = mouse.mouse_behav_param_overrides
    overrides.setdefault("BanditTrial", {})["responsewindow_s"] = 5
    overrides.setdefault("BanditTask", {})["taskblocks_enabled"] = False

    app.mousemanager.save()
finally:
    app.close()
```

To remove an override when it is no longer needed:

```python
from lampyr import Lampyr

app = Lampyr()
try:
    app.mousemanager.load("014-003")
    overrides = app.mouse.mouse_behav_param_overrides

    overrides.get("BanditTrial", {}).pop("responsewindow_s", None)
    if overrides.get("BanditTrial") == {}:
        overrides.pop("BanditTrial")

    app.mousemanager.save()
finally:
    app.close()
```

### Edit overrides directly in mouse JSON

Mouse metadata is saved under the configured mice directory:

```text
<mice_directory>/<MOUSEID>/<MOUSEID>_mouse.lampyr.json
```

For example:

```text
N:/SHARED/Maxwell_LAMPyR_MouseData/014-003/014-003_mouse.lampyr.json
```

Edit only the `mouse_behav_param_overrides` field, preserve the rest of the file, keep valid JSON syntax, and make a backup first. JSON booleans are lowercase (`true`/`false`). The mouse history is stored separately in the history CSV, not in this metadata JSON. Example field value:

```json
"mouse_behav_param_overrides": {
  "BanditTrial": {
    "responsewindow_s": 5
  },
  "BanditTask": {
    "taskblocks_enabled": false,
    "reward_prob_target": 100,
    "reward_prob_offtarget": 0
  }
}
```

Do not edit raw session history files to implement training changes.

## Practical tweak examples

### Lower the session reward cap

Prefer a CLI stop condition for one-off caps:

```bat
lampyr mouse run 014-003 -rl 75
lampyr mouse run 014-003 BanditTask -rl 75 -dl 45
```

This changes only that run. It does not alter task code or mouse metadata.

### Shorten or lengthen the response window

`BanditTrial` has a `responsewindow_s` attribute. Apply a per-mouse override:

```python
mouse.mouse_behav_param_overrides.setdefault("BanditTrial", {})["responsewindow_s"] = 5
```

Remove it once the mouse should return to the task default.

### Change reward probabilities

For `BanditTask`, prefer task-level attributes when possible:

```python
mouse.mouse_behav_param_overrides.setdefault("BanditTask", {}).update({
    "reward_prob_target": 100,
    "reward_prob_offtarget": 0,
})
```

For advanced custom cases, `BanditTrial` also has `rewardprobs_perc`, but overriding trial-level probabilities bypasses the task's normal target-to-probability mapping for each created trial. Use this carefully.

### Disable or enable task blocks

`BanditTask` supports task blocks with `taskblocks_enabled`:

```python
mouse.mouse_behav_param_overrides.setdefault("BanditTask", {})["taskblocks_enabled"] = False
```

Related attributes include `taskblocks_sizerange` and `taskblocks_blockcounttype`; only use them for tasks that define those attributes.

### Adjust wheel thresholds

`BanditTrial` defines `responsethresholds_deg`:

```python
mouse.mouse_behav_param_overrides.setdefault("BanditTrial", {})[
    "responsethresholds_deg"
] = {"Left": 10, "Right": 20}
```

Be aware that some stages may also update this field through global shaping logic, so inspect the mouse after runs and document intentional manual changes.

## Warnings and best practices

- Preserve raw session history. Do not edit saved session JSON/HDF5 files to change training outcomes.
- Prefer `lampyr mouse paradigm ... --stage ...` for normal training progression.
- Prefer CLI stop-condition options for one-off shorter/longer sessions.
- Use mouse behavior overrides only for intentional per-mouse task/trial parameter changes.
- Document every override: mouse ID, date, reason, parameter, old value, new value, and planned removal criteria.
- Verify metadata before running with `lampyr mouse info MOUSEID` and `lampyr mouse paradigm MOUSEID`.
- Remove overrides when no longer needed so the mouse returns to the standard task/paradigm definition.
- Remember that overrides only apply to existing behavior segment attributes and only when future segments are constructed.

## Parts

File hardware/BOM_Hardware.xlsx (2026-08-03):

Sound Attenuation Box
Item # | Item | Notes | Vendor | Catalog # | Unit | Number | Price | Price per Rig | Link
1 | 3/4 in. x 4 ft. x 8 ft. MDF Panel | Each panel makes 2 boxes | Home Depot | 201566 | Panel | 0.5 | $49.98 | $24.99 | https://www.homedepot.com/p/ULTRASTOCK-3-4-in-x-4-ft-x-8-ft-MDF-Panel-D11612490970000/304325742
2 | #8 x 2 in. Coarse Zinc-Plated Phillips Bugle Head Wood Screws (50 per Pack) | Screws | Home Depot | 802692 | Pack (50) | 0.52 | $6.87 | $3.57 | https://www.homedepot.com/p/Everbilt-8-x-2-in-Coarse-Zinc-Plated-Phillips-Bugle-Head-Wood-Screws-50-per-Pack-802692/204283333
3 | 18 fl. oz. Wood Glue | Wood Glue, sufficient for several boxes | Home Depot | 62050 | 18 oz | 0.2 | $7.98 | $1.60 | https://www.homedepot.com/p/Gorilla-18-fl-oz-Wood-Glue-62050/100662003
4 | Mold and Mildew 1 Gal. White Water Based Interior and Exterior Primer, Sealer and Stain-Blocker | Water resistant primer (2 coats) | Home Depot | L204601 | 1 Gal | 0.2 | $38.98 | $7.80 | Mold and Mildew 1 Gal. White Water Based Interior and Exterior Primer, Sealer and Stain-Blocker
5 | 1 Gal. WaterTite LX Low VOC Mold and Mildew-Proof White Water Based Waterproofing Paint | Water resistant paint | Home Depot | 270267 | 1 Gal | 0.1 | $40.98 | $4.10 | https://www.homedepot.com/p/Zinsser-1-Gal-WaterTite-LX-Low-VOC-Mold-and-Mildew-Proof-White-Water-Based-Waterproofing-Paint-270267/206596437
6 | (4-Pack) Solid Bar 3 in. (76 mm) Brushed Stainless Steel Modern Cabinet Handle Drawer Pulls | Cabinet Handles | Home Depot | 731837 | Pack (4) | 0.5 | $19.67 | $9.84 | https://www.homedepot.com/p/Liberty-4-Pack-Solid-Bar-3-in-76-mm-Brushed-Stainless-Steel-Modern-Cabinet-Handle-Drawer-Pulls-P13456L-SS-U1/202824457
7 | 2-Pack Nickel 1 1/4 inch 32mm Overlay Face Frame Self Close Concealed Cabinet Hinges | Cabinet hinges | Home Depot | BP9236SLFF | Pack (2) | 2 | $6.32 | $12.64 | https://www.homedepot.com/p/Amerock-2-Pack-Nickel-1-1-4-inch-32mm-Overlay-Face-Frame-Self-Close-Concealed-Cabinet-Hinges-BP9236SLFF/332609806
8 | Air Compressor Isolator Pads | Feet | Amazon | B0BXWYNYPZ | Pack (4) | 1 | $6.99 | $6.99 | https://www.amazon.com/s?k=B0BXWYNYPZ&i=electronics
9 | Carlisle FoodService Products Cafe Fast Food Cafeteria Tray with Patterned Surface for Cafeterias, Fast Food, And Dining Room, Plastic, 16.31 X 12.06 X 0.7 Inches, Gray, (Pack of 24) | Placed under rig to collect spills | Amazon | CT121623 | Pack (24) | 0.04166666667 | $66.63 | $2.78 | https://www.amazon.com/Carlisle-CT121623-Caf%C3%A9-Standard-Cafeteria/dp/B007726OT0?s=electronics
10 | 24 Pack-12 x 12 x 2 Inches Pyramid Designed Acoustic Foam Panels, Sound Proof Foam Panels Black, High Density and Fire Resistant Acoustic Panels, Sound Panels, Studio Foam for Wall and Ceiling | For sound attentuation | Amazon | B08QN6B2FD | Pack (12) | 0.25 | $34.99 | $8.75 | https://www.amazon.com/Thick-Pyramid-Acoustic-Sound-Panels/dp/B08QN6B2FD?nsdOptOutParam=true
11 | Antrader Stainless Steel Heavy Duty Closet Rod Holder,4Pcs Closet Rod Flange Flange Rod Holder Closet Pole Shower Curtain Rod Pole End Supports Sockets Flange for Diameter 2 inch (51mm) Steel Pipe |  | Amazon | B0CX15W87M | Pack (4) | 1 | $15.99 | $15.99 | https://www.amazon.com/Antrader-Stainless-Curtain-Supports-Diameter/dp/B0CX15W87M?nsdOptOutParam=true
12 | 2 Inch x 36 Inch 1 PCS Dowel Rods Wood Sticks Wooden Dowel Rods - Unfinished Bamboo Sticks - for Crafts and DIYers |  | Amazon | B0CXN25LJJ | Each | 0.5 | $25.99 | $12.99
 | SECTION TOTAL COST (Per Rig) |  |  |  |  |  |  | $112.03
Behavior Rig (Off-Shelf Components)
Item # | Item | Notes | Vendor | Catalog # | Unit | Number | Price | Price per Rig | Link
13 | Aluminum Breadboard 8" x 10" x 1/2", 1/4"-20 Taps |  | Thorlabs | MB810 | pack (5) | 1 | $140.81 | $140.81 | https://www.thorlabs.com/item/MB810
14 | Rubber Feet, Speaker Feet,16 Pack, 1.6“W x 0.4”H | Heavy Duty Speaker Rubber Feet Use for Subwoofer Feet, Road Case Feet，Cutting Board feet,Furniture Feet, 40mm x 10mm, Black |  | Amazon | B096RC5ZCX | pack (16) | 0.25 | $8.99 | $2.25
15 | iexcell 100 Pcs #8-32 x 1 Stainless Steel 304 Hex Socket Button Head Cap Screws Bolts Kit |  | Amazon | B0C5MCZD2X | pack (100) | 0.04 | $7.86 | $0.31
16 | 1/4"-20 Stainless Steel Cap Screw, 5/8" Long, 25 Pack |  | Thorlabs | SH25S063 | pack (25) | 1 | $15.14 | $15.14
17 | 1/4"-20 Stainless Steel Setscrew, 3/4" Long, 25 Pack |  | Thorlabs | SS25S075 | pack (25) | 1 | $8.14 | $8.14
18 | 1/4"-20 Stainless Steel Cap Screw, 1" Long, 25 Pack |  | Thorlabs | SH25S100 | pack (25) | 1 | $12.34 | $12.34
19 | 1/4"-20 Stainless Steel Cap Screw, 3/4" Long, 25 Pack |  | Thorlabs | SH25S075 | pack (25) | 1 | $17.71 | $17.71
20 | Ø1/2" Optical Post, SS, 8-32 Setscrew, 1/4"-20 Tap, L = 4", 5 Pack |  | Thorlabs | TR4-P5 | pack (5) | 0.6 | $32.10 | $19.26 | https://www.thorlabs.com/item/TR4-P5
21 | Ø1/2" Post Holder, Spring-Loaded Hex-Locking Thumbscrew, L = 2", 5 Pack |  | Thorlabs | PH2-P5 | pack (5) | 0.4 | $45.66 | $18.26 | https://www.thorlabs.com/item/PH2-P5
22 | Rotary Encoder - 1024 P/R (Quadrature) |  | Sparkfun | COM-11102 | each | 1 | $48.50 | $48.50 | https://www.sparkfun.com/rotary-encoder-1024-p-r-quadrature.html
23 | Technic Parts 4 pcs TYRE Dia. 62X20 & Rim Dia. 43.2 X 18 | Building Blocks Tyres Compatible with Lego for Kids Boys Toy | Clone of Lego Wheel | Amazon | B0CLYB3QLV | pack (4) | 0.25 | $9.99 | $2.50
24 | Metal Pipe, Aluminum |  | McMaster Car | 89965K15 | 3 ft | 0.1 | $17.77 | $1.78
25 | Hook with Acrylic Adhesive Back |  | McMasterCarr | 96035K21 | 15 ft | 0.006666666667 | $38.70 | $0.26
26 | LOOP with Acrylic Adhesive Back |  | McMasterCarr | 96035K41 | 15 ft | 0.006666666667 | $38.70 | $0.26
27 | Luer Lock Fitting Socket |  | McMaster Carr | 51525K121 | Pack (10) | 0.2 | $4.94 | $0.99
28 | Soft Masterkleer PVC Tubing for Air and Water, 1/16" ID, 1/8" OD |  | McMaster Car | 5233K51 | 100ft | 0.03 | $29.00 | $0.87
29 | White Nylon Spacers |  | McMaster Carr | 94639A534 | Pack (100) | 0.01 | $10.83 | $0.11
30 | Gorilla 2 Part Epoxy, Incredibly Strong Bonding, 5 Minute Set, 0.85 oz | Water Resistant, Bonds Uneven or Vertical Surfaces, Easy-to-Use Syringe |  | Amazon | B001Z3C3AG | each | 0.1 | $5.97 | $0.60
31 | 2-way Normally Closed Solenoid Valves |  | NResearch | 161K011 | each | 1 | $86.17 | $86.17
32 | Luer Lock Fitting Plug |  | McMaster Carr | 51525K211 | Pack (10) | 0.2 | $4.79 | $0.96
33 | Zero Dead Volume Barb Fittings, 10-32 x 1/16, Option 2: PCTFE |  | NResearch | FITM328 | each | 2 | $10.28 | $20.56
34 | Blunt tip needles |  | McMaster Carr | 75165A246 | Pack (50) | 0.02 | $8.24 | $0.16 | https://www.amazon.com/Rubyfluid-FLSRUBYFLUIDSS-RubyFluid-Stainless-Steel/dp/B007BGYQEC?nsdOptOutParam=true
35 | Ruby's Stainless Steel Soldering Flux |  | Amazon | B007BGYQEC | 1 Pint | 0.01 | $19.99 | $0.20 | https://www.amazon.com/Oatey-Solder-Silver-Safe-53061/dp/B017085DUG?nsdOptOutParam=true
36 | Oatey Solder 1Oz Silver Safe Flo 53061 |  | Amazon | B017085DUG | 1Oz | 0.05 | $12.48 | $0.62 | https://www.thorlabs.com/item/PH1-P5
37 | Right-Angle Clamp for Ø1/2" Posts, 3/16" Hex, 5 Pack |  | Thorlabs | RA90-P5 | pack (5) | 0.2 | $56.45 | $11.29 | https://www.thorlabs.com/item/RA90-P5
38 | Ø1/2" Post Holder, Spring-Loaded Hex-Locking Thumbscrew, L = 0.5", 5 Pack |  | Thorlabs | PH1-P5 | pack (5) | 0.6 | $41.70 | $25.02 | https://www.thorlabs.com/item/BA1S-P5
39 | Mounting Base, 1" x 2.3" x 3/8", 5 Pack |  | Thorlabs | BA1S-P5 | pack (5) | 0.4 | $27.08 | $10.83 | https://www.thorlabs.com/item/TR075-P5
40 | Arducam 100fps Mono Global Shutter USB Camera, 720P OV9281 UVC Webcam Module with Low Distortion M12 Lens Without Microphones, for Computer, Laptop, Android and Raspberry Pi |  | Amazon | B096M5DKY6 | each | 1 | $49.99 | $49.99 | https://www.adafruit.com/product/1143
41 | Ø1/2" Optical Post, SS, 8-32 Setscrew, 1/4"-20 Tap, L = 0.75", 5 Pack |  | Thorlabs | TR075-P5 | pack (5) | 0.2 | $25.92 | $5.18 | https://www.thorlabs.com/item/TR2-P5
42 | Micro Servo - MG90D High Torque Metal Gear |  | Adafruit | 1143 | each | 1 | $9.95 | $9.95
43 | Ordro LN-3 IR Night Vision Light for Enhancing Camera Night Shooting Visibility, 1/4 Hot Shoe Compatible DSLR/Ordro Camera, 850nm IR Light USB Rechargeable IR Photography Light (Ghost Hunting Device) |  | Amazon | B09KGS84QN | each | 1 | $27.99 | $27.99 | https://www.amazon.com/Arducam-Distortion-Microphones-Computer-Raspberry/dp/B096M5DKY6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
44 | Ø1/2" Optical Post, SS, 8-32 Setscrew, 1/4"-20 Tap, L = 2", 5 Pack |  | Thorlabs | TR2-P5 | pack (5) | 0.2 | $28.38 | $5.68 | https://www.amazon.com/ORDRO-Camcorder-Compatible-Rechargeable-Photography/dp/B09KGS84QN
45 | PRV AUDIO Soft Dome Tweeters 240 Watts 4 Ohm TW150SD-4 with Built-in Crossover, 32 mm Silk Dome, Neodymium Magnet for Car Audio and Motorcycle Systems Easy Flush Mount (Pair) | Received | Amazon | B0C3YGJ8VH | pack of 2 | 6 | $49.91 |  | https://www.amazon.com/Building-Blocks-Technic-Parts-Compatible/dp/B0CLYB3QLV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
 | SECTION TOTAL COST (Per Rig) |  |  |  |  |  |  | $544.69
Behavior Rig (Custom Components)
Item # | Item | Notes | Vendor |  | Unit | Number | Price | Price per Rig | File
46 | Headplate Holder Arm |  | eMachineShop |  | Quote (20) | 0.1 | $141.84 | $14.18 | headplateholder_arm.ems
47 | Rotary Encoder/Platform | PLA Plastic | 3DPrint (in-house) |  | each | 1 | ~$2 | $2 | mouseplatform_part47.stl
48 | Rotary Encoder/Wheel Adapter | Tough Resin | 3DPrint (in-house) |  | each | 1 | ~$5 | $5 | encoderwheeladapter_part48.stl
49 | Camera Mount | PLA Plastic | 3DPrint (in-house) |  | each | 1 | ~$2 | $2 | cameramount_part49.stl
50 | Servomotor Mount | PLA Plastic | 3DPrint (in-house) |  | each | 1 | ~$2 | $2 | servomotormount_part50.3mf
51 | Tweeter Mount | PLA Plastic | 3DPrint (in-house) |  | each | 1 | ~$2 | $2 | speakerholder_part51.stl
52 | Touchscreen Mount | PLA Plastic | 3DPrint (in-house) |  | each | 1 | ~$2 | $2 | touchscreenmount_Part52.3mf
53 | Solenoid Mount | PLA Plastic | 3DPrint (in-house) |  | each | 2 | ~$1 | $1 | solenoidholder_part53_variant1.stl
 | SECTION TOTAL COST (Per Rig) |  |  |  |  |  |  | $30.18
Computer/Electronic Control
Item # | Item | Notes | Vendor | Catalog # | Unit | Number | Price | Price per Rig | Link
54 | Arduino Uno |  | Digikey | 1050-1024-ND | each | 1 | $27.60 | $27.60 | https://store-usa.arduino.cc/products/arduino-uno-rev3
55 | Custom PCB shield | See included "HudaHub" file and instructions for ordering | JLCPCB | Custom | Quote (20) Includes shipping | 0.05 | $191.30 | $9.57 | https://jlcpcb.com/
56 | HiLetgo 20pcs 40P 2.54mm Pitch Single Row Pin Header Strip 40Pin 2.54mm Pitch |  | Amazon | B07R5QDL8D | each | 4 | $5.48 | $21.92
57 | Reed Relay edr201a0500 |  | Jameco | 106463 (SKU:EDR201A05Z) | each | 1 | $2.49 | $2.49
58 | Ultra Small DT: OptiPlex Micro Form Factor (7020)OptiPlex Micro Form Factor 7020 |  | Dell | 210-BKXM | each | 1 | $640.00 | $640.00 | https://www.dell.com/en-us/shop/desktop-computers/optiplex-micro-form-factor/spd/optiplex-7020-micro
59 | Raspberry Pi Screen 7inch Monitor IPS 1024x600 HDMI Capacative 7'' Touch Screen Monitors Compatible with 3B+/3/2 B/B+/ Banana Pi Windows10/8.1/8/7 Driver Free 5-Point Raspberry pi Display |  | Amazon | B0BZGW51FY | each | 1 | $39.99 | $39.99
60 | Raspberry Pi 5 - 8GB | Recommended replacement for above | Adafruit | DEV-23551 | each | 1 | $180.00 | $180.00 | https://www.sparkfun.com/raspberry-pi-5-8gb.html
 | SECTION TOTAL COST (Per Rig) |  |  |  |  |  |  | $281.57
Surgical Implant (Custom)
Item # | Item | Notes | Vendor |  | Unit |  | Price | Price per Rig | File
61 | Headplate (Implant) |  | eMachineShop |  | Quote (1000) |  | 371.41 | $0.00 | headplate.ems
 | GRAND TOTAL PER RIG |  |  |  |  |  |  | $968.46
 |  |  |  |  |  |  |  | $1568.47

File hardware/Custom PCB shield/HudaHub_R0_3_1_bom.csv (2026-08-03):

Designator | Footprint | Quantity | Value | LCSC Part #
C1 | C_0603 | 1 | 10nF | C57112
C2, C3, C4, C5, C8 | CL05B104KO5NNNC | 5 | CL05B104KO5NNNC | C1525
C6 | RVT1V151M0810 | 1 | RVT1V151M0810 | C38513
C7 | C_0805 | 1 | 22uF | C45783
D1 | D_SMA | 1 | SS12 | C18199177
D2, D4 | D_SMA | 2 | M4 | C18199095
D3, D5, D6, D7 | 1N4148WS_T4 | 4 | 1N4148WS_T4 | C2128
DC1 | DC005_C431533 | 1 | DC005_C431533 | C431533
H1 | PZ254V-11-06P | 1 | PZ254V-11-06P | C492405
H2 | PZ254V-11-08P | 1 | Digital/PWM | C492407
H3 | PZ254V-11-08P | 1 | Power | C492407
H4 | PZ254V-11-10P | 1 | Digital/PWM | C492409
L1 | FHD4020S-330MT | 1 | FHD4020S-330MT | C602034
LED1 | 0805G_Green | 1 | 0805G_Green | C2297
Q1, Q2 | Q_SOT-23 | 2 | MMBT2222A | C7420351
Q3, Q4 | TIP122_C16283 | 2 | TIP122_C16283 | C16283
R1, R7 | R_0402 | 2 | 10kΩ | C25744
R10, R11 | R_0402 | 2 | 1kΩ | C11702
R12, R2 | R_0603 | 2 | 10kΩ | C25804
R13 | R_1206 | 1 | 0Ω | C17888
R3, R8 | R_0603 | 2 | 10MΩ | C7250
R4 | R_0805 | 1 | 3.3kΩ | C26010
R5 | R_1206 | 1 | 1kΩ | C4410
R6 | R_0603 | 1 | 2.4kΩ | C22940
R9 | R_0603 | 1 | 47kΩ | C25819
SK1 | Z-10014320100100 | 1 | Z-10014320100100 | C190815
SW1, SW2, SW3 | K2-1102DP-C4SW-04 | 3 | K2-1102DP-C4SW-04 | C110153
TPS5430DDAR1 | TPS5430DDAR | 1 | U | C9864
U1 | DB125-2_54-2P-GN | 1 | DB125-2_54-2P-GN | C918120
U2 | DB125-2_54-4P-GN | 1 | DB125-2_54-4P-GN | C918122
U3 | DB125-2_54-8P-GN | 1 | DB125-2_54-8P-GN | C918126
U4 | DB125-2_54-12P-GN | 1 | DB125-2_54-12P-GN | C918129

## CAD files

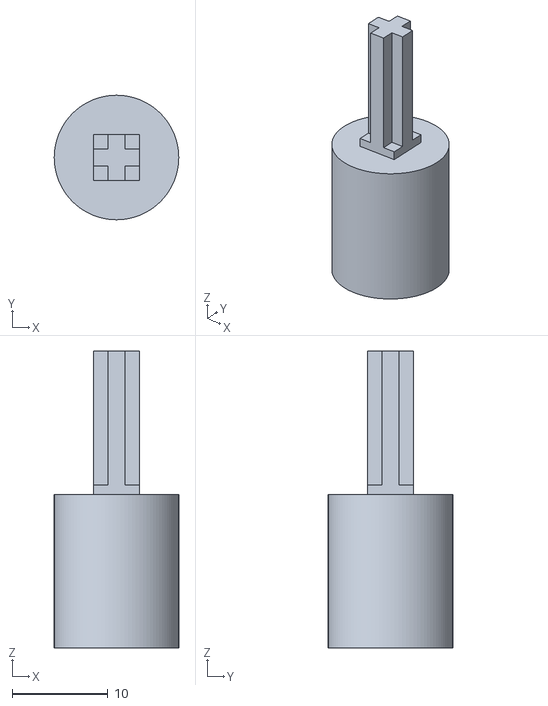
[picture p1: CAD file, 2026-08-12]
hardware/3d models/encoderwheeladapter_part48.stl
13.0 x 13.0 x 31.0

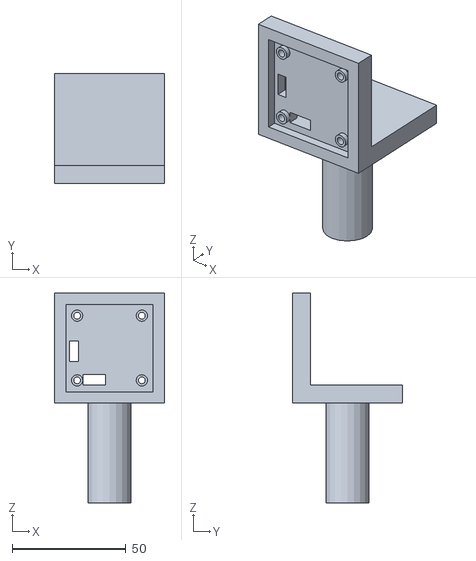
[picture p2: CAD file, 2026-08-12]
hardware/3d models/cameramount_part49.stl
48.5 x 48.5 x 92.5

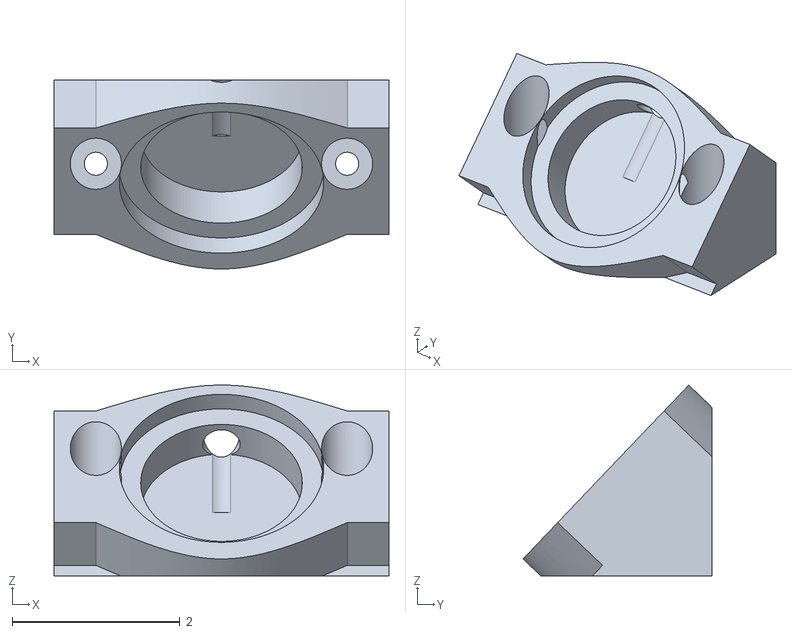
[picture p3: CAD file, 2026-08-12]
hardware/3d models/speakerholder_part51.stl
4.00 x 2.26 x 2.28

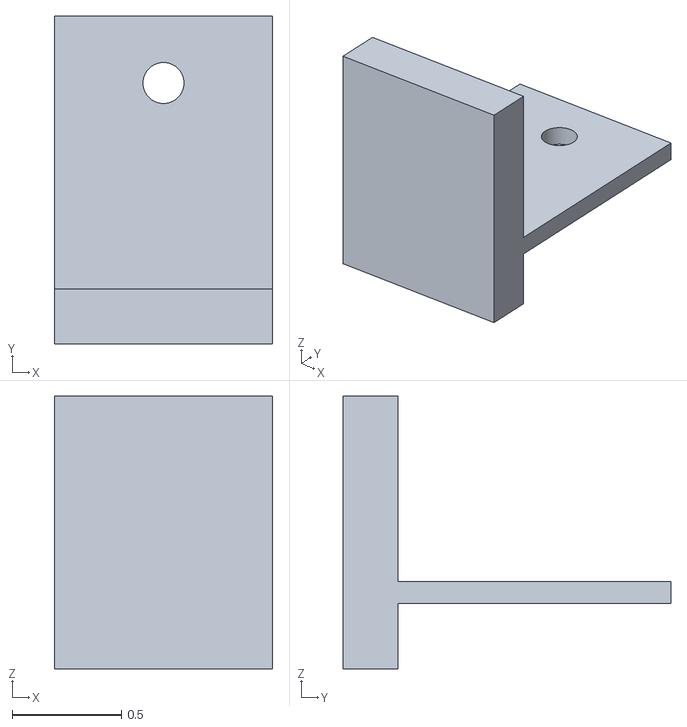
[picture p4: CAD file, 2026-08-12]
hardware/3d models/solenoidholder_part53_variant1.stl
1.00 x 1.50 x 1.25

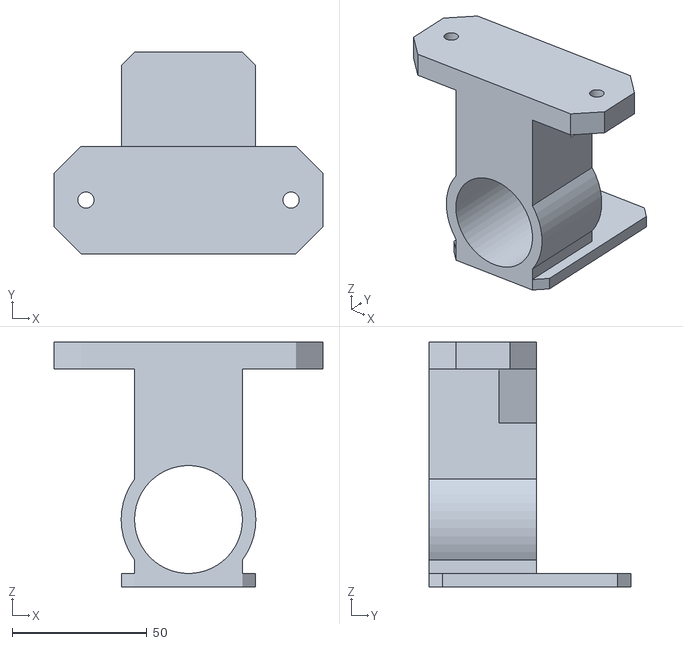
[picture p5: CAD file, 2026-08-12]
hardware/3d models/mouseplatform_part47.stl
100.0 x 75.0 x 91.0

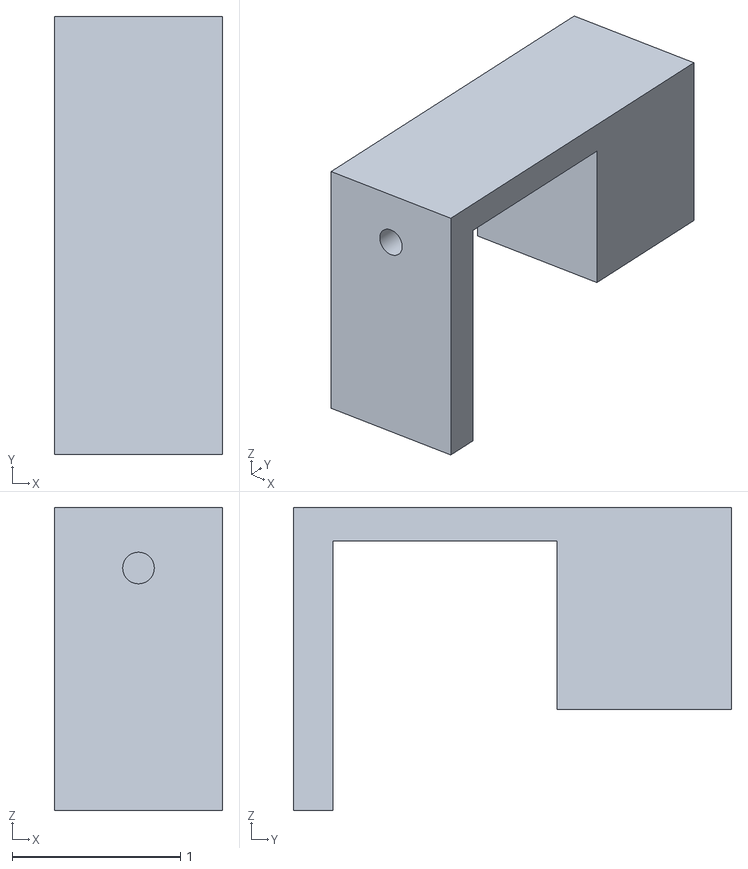
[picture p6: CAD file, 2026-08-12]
hardware/3d models/solenoidholder_part53_variant2.stl
1.00 x 2.60 x 1.80

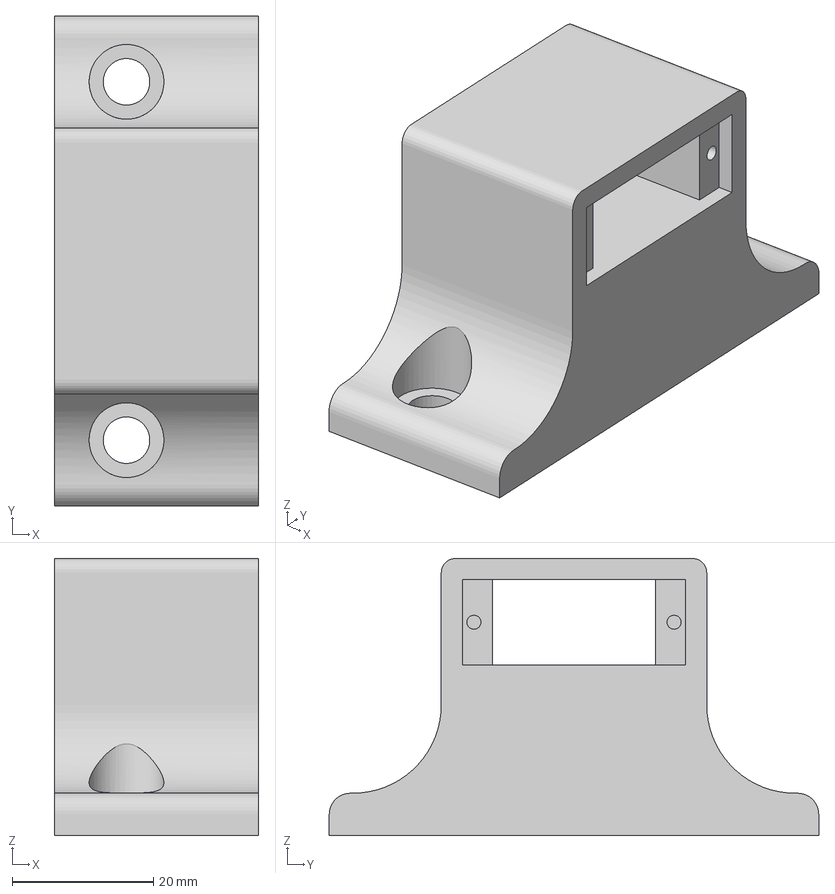
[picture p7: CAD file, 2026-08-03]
hardware/3d models/servomotormount_part50.3mf
29.0 x 69.4 x 39.3 mm

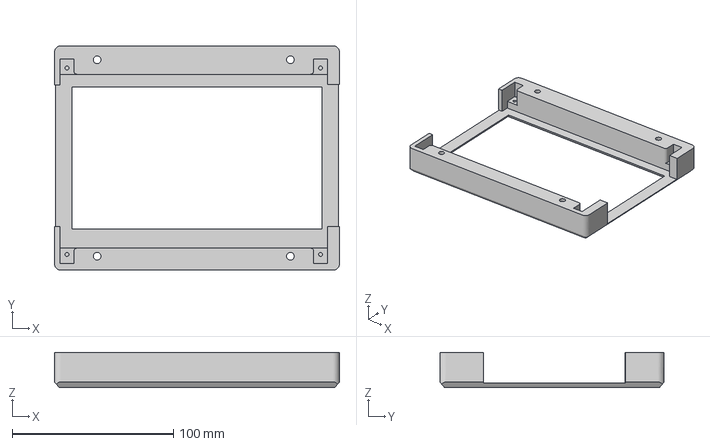
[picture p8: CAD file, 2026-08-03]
hardware/3d models/touchscreenmount_Part52.3mf
177.0 x 139.4 x 22.0 mm

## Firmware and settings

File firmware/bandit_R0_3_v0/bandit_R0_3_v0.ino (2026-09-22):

// This Firmware is intended for an Arduino UNO with the HudaHubR0.3 Shield

#include <Encoder.h>
#include <Servo.h>
#include <TaskScheduler.h>

// -----------------------------------------------------------------------------
// Pin Definitions
// -----------------------------------------------------------------------------

#define RIG_ID "BanditHudaHub_1"

#define SPEAKERPIN          6
#define REWARDPIN           9
#define MANUALREWARDPIN     13
#define LASERPIN            11
#define CAM_PIN

#define LICKOMETERDIGPIN    A2
#define LICKOMETERANALOGPIN A3

#define SERVOMOTORPIN       5

#define ROTARYPIN1          2
#define ROTARYPIN2          3

// -----------------------------------------------------------------------------
// Task Periods
// -----------------------------------------------------------------------------

#define LICK_PERIOD_MS      10
#define ROTARY_PERIOD_MS    20
#define CAM_PULSE_PERIOD_MS 50

// -----------------------------------------------------------------------------
// Hardware
// -----------------------------------------------------------------------------

Scheduler runner;

Encoder rotary(ROTARYPIN1, ROTARYPIN2);
Servo wheelLock;

// -----------------------------------------------------------------------------
// State
// -----------------------------------------------------------------------------

// Laser
bool rampingDown = false;
bool rampPending = false;
uint32_t rampRequestMs = 0;
uint32_t rampDelayMs = 0;
uint32_t rampStartMs = 0;
uint32_t rampDurationMs = 0;
int rampStartPWM = 255;

// Rotary
long rotarypos = 0;
long rotarypos_last = 0;
long rotarydiff = 0;

// Lick
int currentlickanalog = 0;
int currentlickdigital = 0;

// Reward
bool rewarding = false;
uint32_t rewardStart = 0;
uint32_t rewardsize = 500;      // microseconds
uint32_t rewardError = 0;

// Manual reward button
bool manualRewardState = HIGH;
bool manualRewardLastState = HIGH;

// Lock
int angle = 0;

// Loop frequency measurement
bool measureLoopRequested = false;

uint32_t loopCounter = 0;
uint32_t loopCounterStart = 0;

bool pauseAfterReport = false;
uint32_t pauseStart = 0;

// -----------------------------------------------------------------------------
// Reporting
// -----------------------------------------------------------------------------

void reportCommand(char cmd)
{
    Serial.print(millis());
    Serial.print("\tC\t");
    Serial.println(cmd);
}

void reportRotary()
{
    rotarypos = rotary.read();

    rotarydiff = rotarypos_last - rotarypos;

    Serial.print(millis());
    Serial.print("\tR\t");
    Serial.println(rotarydiff);

    rotarypos_last = rotarypos;
}

void reportLick()
{
    currentlickanalog = analogRead(LICKOMETERANALOGPIN);
    currentlickdigital = analogRead(LICKOMETERDIGPIN);

    Serial.print(millis());
    Serial.print("\tA\t");
    Serial.println(currentlickanalog);

    Serial.print(millis());
    Serial.print("\tL\t");
    Serial.println(currentlickdigital);
}

void reportRewardSize()
{
    Serial.print(millis());
    Serial.print("\tW\t");
    Serial.println(rewardsize);
}

void reportReward()
{
    Serial.print(millis());
    Serial.print("\tG\t");
    Serial.println(rewardsize);
}

void reportManualReward()
{
    Serial.print(millis());
    Serial.print("\tM\t");
    Serial.println(1);
}

void reportTime()
{
    Serial.print(millis());
    Serial.print("\tT\t");
    Serial.println(millis());
}

void reportRewardError()
{
    Serial.print(millis());
    Serial.print("\tE\t");
    Serial.println(rewardError);
}

void reportLoopHz(uint32_t hz)
{
    Serial.print(millis());
    Serial.print("\tF\t");
    Serial.println(hz);
}

// -----------------------------------------------------------------------------
// Reward Handling
// -----------------------------------------------------------------------------

void giveReward()
{
    if (rewarding)
        return;

    digitalWrite(REWARDPIN, HIGH);

    rewardStart = micros();
    rewarding = true;
}

void checkReward()
{
    if (!rewarding)
        return;

    uint32_t elapsed = micros() - rewardStart;

    if (elapsed >= rewardsize)
    {
        rewardError = elapsed - rewardsize;

        digitalWrite(REWARDPIN, LOW);

        rewarding = false;
    }
}

// -----------------------------------------------------------------------------
// Manual Reward Button
// -----------------------------------------------------------------------------

void checkManualReward()
{
    manualRewardState = digitalRead(MANUALREWARDPIN);

    if (manualRewardLastState == HIGH &&
        manualRewardState == LOW)
    {
        reportManualReward();

        giveReward();

        reportReward();
    }

    manualRewardLastState = manualRewardState;
}

// -----------------------------------------------------------------------------
// Commands
// -----------------------------------------------------------------------------

void executeCommand(char cmd)
{
    reportCommand(cmd);
    switch (cmd)
    {
        case 'p':
            tone(SPEAKERPIN, 1000, 100);
            break;

        case 'r':
            tone(SPEAKERPIN, 10000, 100);
            break;

        case 'b':
            tone(SPEAKERPIN, 4000, 100);
            break;

        case 'w':
        {
            String str = Serial.readStringUntil('\n');

            rewardsize = str.toInt();

            reportRewardSize();
            break;
        }

        case 'g':
        {
            giveReward();

            reportReward();
            break;
        }

        case 'z': // Start "zap" protocol for laser stim
        {
            rampingDown = false;
            rampPending = false;
            analogWrite(LASERPIN, 255);
            break;
        }

        case 'x': // Hardcutoff to laser stim
        {
            rampingDown = false;
            rampPending = false;
            analogWrite(LASERPIN, 0);
            break;
        }

        case 'c': // Slow rampdown to laser stim
        {
            String str = Serial.readStringUntil('\n');
            int comma = str.indexOf(',');
            String durationStr = comma >= 0 ? str.substring(0, comma) : str;
            String delayStr = comma >= 0 ? str.substring(comma + 1) : "0";

            rampDurationMs = durationStr.toInt() * 1000UL;
            rampDelayMs = max(0L, delayStr.toInt());
            rampRequestMs = millis();
            rampingDown = false;
            rampPending = rampDelayMs > 0;
            if (!rampPending)
            {
                rampStartMs = millis();
                rampStartPWM = 255;
                rampingDown = true;
            }

            break;
        }

        case 'l': // Lock the wheel
        {
            wheelLock.write(60);
            break;
        }

        case 'u': // Unlock the wheel
        {
            wheelLock.write(90);
            break;
        }

        case 'a': // Set to specific angle
        {
            String str = Serial.readStringUntil('\n');

            angle = str.toInt();
            wheelLock.write(angle);
            break;
        }

        case 't':
        {
            reportTime();
            break;
        }

        
        case 'i':
        {
            Serial.print(millis());
            Serial.print("\tI\t");
            Serial.println(RIG_ID);
            break;
        }
        case 'e':
        {
            reportRewardError();
            break;
        }

        case 'f':
        {
            measureLoopRequested = true;

            loopCounter = 0;
            loopCounterStart = millis();

            break;
        }
    }
}

void handleSerial()
{
    while (Serial.available())
    {
        char cmd = (char)Serial.read();
        executeCommand(cmd);
    }
}

// -----------------------------------------------------------------------------
// Scheduled Tasks
// -----------------------------------------------------------------------------

Task lickTask(
    LICK_PERIOD_MS,
    TASK_FOREVER,
    &reportLick
);

Task rotaryTask(
    ROTARY_PERIOD_MS,
    TASK_FOREVER,
    &reportRotary
);

// -----------------------------------------------------------------------------
// Setup
// -----------------------------------------------------------------------------

void setup()
{
    Serial.begin(115200);

    pinMode(LED_BUILTIN, OUTPUT);

    pinMode(SPEAKERPIN, OUTPUT);

    pinMode(REWARDPIN, OUTPUT);
    digitalWrite(REWARDPIN, LOW);

    pinMode(MANUALREWARDPIN, INPUT_PULLUP);

    pinMode(LICKOMETERDIGPIN, INPUT);
    pinMode(LICKOMETERANALOGPIN, INPUT);

    wheelLock.attach(SERVOMOTORPIN);
    wheelLock.write(90);

    runner.init();

    runner.addTask(lickTask);
    runner.addTask(rotaryTask);

    lickTask.enable();
    rotaryTask.enable();
}

// -----------------------------------------------------------------------------
// Main Loop
// -----------------------------------------------------------------------------

void loop()
{
    // -------------------------------------------------------------
    // Post-report pause
    // -------------------------------------------------------------

    if (pauseAfterReport)
    {
        if ((millis() - pauseStart) >= 1000)
        {
            pauseAfterReport = false;
        }

        return;
    }

    // -------------------------------------------------------------
    // Normal operation
    // -------------------------------------------------------------

    handleSerial();

    checkManualReward();

    checkReward();

    runner.execute();

    // -------------------------------------------------------------
    // Loop frequency measurement
    // -------------------------------------------------------------

    if (measureLoopRequested)
    {
        loopCounter++;

        if ((millis() - loopCounterStart) >= 1000)
        {
            reportLoopHz(loopCounter);

            measureLoopRequested = false;

            pauseAfterReport = true;
            pauseStart = millis();
        }
    }

    // -------------------------------------------------------------
    // Laser rampdown
    // -------------------------------------------------------------
    if (rampPending && millis() - rampRequestMs >= rampDelayMs)
    {
        rampPending = false;
        rampStartMs = millis();
        rampStartPWM = 255;
        rampingDown = true;
    }

    if (rampingDown)
    {
        uint32_t elapsed = millis() - rampStartMs;

        if (elapsed >= rampDurationMs)
        {
            analogWrite(LASERPIN, 0);
            rampingDown = false;
        }
        else
        {
            int pwm =
                rampStartPWM -
                ((long)rampStartPWM * elapsed) / rampDurationMs;

            analogWrite(LASERPIN, pwm);
        }
    }
}

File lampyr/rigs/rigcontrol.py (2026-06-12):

# -*- coding: utf-8 -*-
"""
Created on Wed May 14 15:02:37 2025

@author: mm4114
"""

import threading
from serial.tools import list_ports
import serial
from dataclasses import dataclass, field
from collections import defaultdict
import time

class ArduinoBanditRig_0:
    """
    High-level interface to the Arduino-based bandit rig (hardware version 0).

    Wraps a :class:`SerialMonitor` and exposes named sub-objects for each
    hardware component: wheel encoder, lick sensor, speaker, and sipper.

    Attributes
    ----------
    serial : SerialMonitor
        Serial communication handler.
    data : SerialData
        Shared data store populated by the serial monitor thread.
    wheel : Wheel
        Wheel encoder interface.
    licks : Lick
        Lick sensor interface.
    play : Speaker
        Speaker/tone interface.
    reward : Sipper
        Water sipper interface.
    """

    class _Measure():
        """Base class for rig components that read from ``SerialData``."""

        def __init__(self, parent):
            self.data = parent.data

    class _Control():
        """Base class for rig components that write to the serial port."""

        def __init__(self, parent):
            self.serial = parent.serial

    class Wheel(_Measure):
        """
        Rotary wheel encoder interface.

        Reads raw encoder ticks from report type ``'R'`` and converts to
        degrees (4096 ticks per revolution).
        """

        def __init__(self, *args, **kwargs):
            super().__init__(*args, **kwargs)
            self.home()

        def movement_total_since(self, time):
            """
            Return the net signed displacement (degrees) since ``time``.

            Equivalent to ``positive_component - negative_component``.

            Parameters
            ----------
            time : float
                Unix timestamp; only events after this time are counted.

            Returns
            -------
            float
                Net displacement in degrees.
            """
            components = self.movement_components_since(time)
            return components[1] - components[0]

        def movement_since(self, time):
            """
            Return the sum of all encoder ticks (signed) since ``time``, in degrees.

            Parameters
            ----------
            time : float
                Unix timestamp; only events after this time are counted.

            Returns
            -------
            float
                Signed total displacement in degrees.
            """
            return sum(self.data.get_reportvals_since('R', time))/4096*360

        def movement_components_since(self, time):
            """
            Return negative and positive movement components separately.

            Parameters
            ----------
            time : float
                Unix timestamp; only events after this time are counted.

            Returns
            -------
            tuple of (float, float)
                ``(negative_degrees, positive_degrees)`` — both values are
                expressed as non-negative magnitudes for the respective
                directions.
            """
            sum_positive = sum(x for x in self.data.get_reportvals_since('R', time)
                               if x > 0)/4096*360
            sum_negative = sum(x for x in self.data.get_reportvals_since('R', time)
                               if x < 0)/4096*360
            return sum_negative, sum_positive

        def angle(self):
            """
            Return the current wheel angle relative to the last :meth:`home` call.

            Returns
            -------
            float
                Signed displacement in degrees from the home position.
            """
            return self.movement_since(self.home_t)

        def home(self):
            """
            Reset the wheel home position to the current time.

            Subsequent calls to :meth:`angle` will measure displacement from
            this moment.
            """
            self.home_t = time.time()

    class Lick(_Measure):
        """Lick detector interface reading report type ``'L'``."""

        def since(self, time):
            """
            Count the number of lick onset events since ``time``.

            Detects lick onsets as low-to-high threshold crossings (threshold
            512) in the raw lick signal.

            Parameters
            ----------
            time : float
                Unix timestamp; only events after this time are counted.

            Returns
            -------
            int
                Number of detected lick onsets.
            """
            lickdat = self.data.get_reportvals_since('L', time)
            lcount = 0
            for l1, l2 in zip(lickdat,lickdat[1:]):
                if l1 < 512 and l2 > 512:
                    lcount += 1
            return lcount
    
    class WheelLock(_Control):
        def lock(self):
            self.serial._writeserial('l')
            
        def unlock(self):
            self.serial._writeserial('u')
        
        def to_angle(self, angle):
            self.serial._writeserial(f'a{angle}\n')

    class Speaker(_Control):
        """Speaker interface for playing tones via the rig Arduino."""

        def begintrialtone(self):
            """Play the trial-start tone (serial command ``'b'``)."""
            self.serial._writeserial('b')

        def responsetone(self):
            """Play the response tone (serial command ``'r'``)."""
            self.serial._writeserial('r')

        def punishtone(self):
            """Play the punishment tone (serial command ``'p'``)."""
            self.serial._writeserial('p')

    class Sipper(_Control):
        """Water sipper interface for delivering liquid rewards."""

        def give(self):
            """Dispense one reward (serial command ``'g'``)."""
            self.serial._writeserial('g')

        def setsize(self, size : int):
            """
            Set the sipper reward size on the Arduino.

            Parameters
            ----------
            size : int
                Dispense size value (arbitrary Arduino units, calibrated to
                ~5 µl per reward).
            """
            self.serial._writeserial('w')
            self.serial._writeserial(f'{size}\n')

    def __init__(self, customserialmonitor=None):
        """
        Initialise the rig, creating a :class:`SerialMonitor` if none is provided.
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

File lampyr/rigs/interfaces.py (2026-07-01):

# -*- coding: utf-8 -*-
"""
Created on Tue Jun 23 12:52:15 2026

@author: mm4114
"""

from lampyr.rigs.abstract import AbstractInterface, InterfaceData
import numpy as np
import threading
import time


class SerialInterface_ArduinoTRV(AbstractInterface):
    def setup(self, baud=115200, timeout=1):
        self.baud = baud
        self.timeout = timeout
        self._find_device()
        self.data = InterfaceData(
            ['arduino_time', 'unix_time', 'report_value'])
        self.abort_flag = False
        self.stop_flag = False
        self.thread = None

    def _find_device(self):
        from serial.tools import list_ports
        import serial
        """
        Scan COM ports for an Arduino and open the first one found.

        Raises
        ------
        RuntimeError
            If no Arduino is found in the list of available serial ports.
        """
        ports = list_ports.comports()
        ports = [p for p in ports if 'Arduino' in p.description]
        if not ports:
            raise RuntimeError(
                'No Arduino device found. Check USB connection.')
        port = ports[0]
        self.ser = serial.Serial(port.device, self.baud, timeout=self.timeout)
        time.sleep(2)
        self.ser.reset_input_buffer()
        self.ser.flush()

    def start(self):
        if self.thread is not None:
            self.stop_flag = False
            return
        self.thread = threading.Thread(target=self.listen, daemon=True)
        self.thread.start()
        time.sleep(2)
            

    def listen(self):
        """
        Background thread target: continuously read from the serial port.

        Resets the input buffer, then loops calling :meth:`_readserial` until
        the abort flag is set.  Resets the abort flag on exit.
        """
        time.sleep(1)
        self.ser.reset_input_buffer()
        self.ser.flush()
        while not self.abort_flag:
            while not self.stop_flag:
                try:
                    self._readserial()
                except Exception as error:
                    print(f'WARNING! Unknown serial read error occurred. {error}')
                time.sleep(0.001)
            time.sleep(0.001)

        self.abort_flag = False

    def _readserial(self):
        """
        Drain the serial buffer and store all valid incoming lines.

        Parses each line as ``arduino_timestamp<TAB>event_type<TAB>value``.
        Malformed lines and unicode errors are printed as warnings.  All
        successfully parsed entries are logged into the interface data object.

        Returns
        -------
        list of tuple
            Newly parsed ``(unix_time, [arduino_time, event_type, value])``
            entries from this read cycle.
        """
        responses = []
        while self.ser.in_waiting > 0:
            try:
                response = self.ser.readline().decode().strip()
            except UnicodeDecodeError as error:
                print(error)
                print(
                    'WARNING: UnicodeDecodeError detected. If this reoccurs, restart your script!!!!')
                break
            response = response.split('\t')
            # print(response)
            if len(response) == 3:
                try:
                    timestamp = int(response[0])
                    event_type = str(response[1])
                    value = int(response[2])
                    responses.append(
                        (time.time(), [timestamp, event_type, value]))
                except ValueError as e:
                    print(f"ValueError processing data: {response} - {e}")
            else:
                print(f"Received unexpected data format: {response}")
        for unix_time, (arduino_time, report_type, report_value) in responses:
            self.data.log_report(report_type, arduino_time=arduino_time,
                                 unix_time=unix_time,
                                 report_value=report_value
                                 )
        return responses

    def send_command(self, cmd):
        cmdent = f'{cmd}\n'
        self.ser.write(cmdent.encode())
    
    def stop(self):
        self.stop_flag = True

    def disconnect(self):
        self.abort_flag = True
        self.stop_flag = True
        if self.thread is not None:
            self.thread.join(timeout=2)
        self.ser.close()

    def dump(self):
        return {'COM PORT': self.ser.port,
                'BAUD': self.ser.baudrate,
                'BYTESIZE': self.ser.bytesize}
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

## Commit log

2026-03-12 Add analysis tools, file IO, and bandit updates
    Adds a set of analysis utilities and experiment tooling and updates bandit behavior logic.
    - New lampyr.analysis package: data, traces, time, segments, longtidy and __init__ providing
    multi-session dataset handling, dynamic trace extraction, time translation, event/segment
    extraction and a parquet-based caching decorator.
    - New lampyr/files.py: HDF5/JSON/CSV/pickle helpers plus session/mouse save/load logic to persist
    Lampyr Session rigdata and metadata.
    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
2026-03-12 Adjust pins, calibration sizes, and update script
    Reassign Arduino pins in firmware: SPEAKERPIN 11 -> 5, REWARDPIN 9 -> 12 to match updated hardware wiring. Reduce calibration dispense sizes in RigManager from [20000, 30000, 50000] to [5000, 10000, 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
2026-03-13 Clear SPI control register (SPCR) in setup
    Initialize SPI hardware to a known disabled state by setting SPCR = 0 in setup(). This prevents unintended SPI activity or bus conflicts on startup and ensures pins are in a defined state.
2026-03-13 Fix 14 bugs found during code review
    Critical fixes:
    - managers/data.py: fix _logfailure using wrong attribute name (config_failsafe -> config_failsafe_data)
    - managers/data.py: fix mouseexists checking wrong filename (mouseid.lampyr.json -> {mouseid}_mouse.lampyr.json)
    - managers/data.py: fix mouselist building mouseidlist from unfiltered candidate_mice instead of mousepaths
    - managers/data.py: fix failsafe key mismatch ('session' vs 'sessions') in _runfailsafecleanup
    - rigs/rigcontrol.py: fix unguarded ports[0] IndexError when no Arduino is connected
    - rigs/rigcontrol.py: fix get_reportvals_since off-by-one and single-element edge case; rewrite with forward scan
    - segments/behavior.py: fix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
    [abstract.py, rigcontrol.py]
2026-03-16 Use sipper_calib and weight-based calibration
    Increase default sipper_calib from 4000 to 10000 and update the calibration routine to use weight (g) inputs instead of water level (ml). Calibration now runs 100 dispensing trials, computes dvol as 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
2026-03-16 Init reward pin LOW; clamp sipper min
    Set REWARDPIN to LOW on Arduino startup to prevent accidental reward pulses (firmware/banditv0_0_0/banditv0_0_0.ino). In lampyr/managers/hardware.py enforce a minimum sipper calibration value (est_sipp) of 10000 so dispense size calculations don't use values below that threshold.
    [banditv0_0_0.ino]
2026-03-16 Adjust reward timing and dispense size range
    Decrease the inter-reward delay in the 200-iteration reward loop from 0.8s to 0.4s to speed up calibration/giving cycles. Change candidate dispense sizes from [est/2, est, est*2] to [est*(2/3), est, 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
2026-03-17 Lower sipper overwrite threshold to 6000
    Reduce the sanity-check threshold for est_sipp from 10000 to 6000 so estimated sipper values in the 6001–10000 range are preserved instead of being clamped to 10000. This allows dsizes/dvols to be co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
2026-03-17 Use class annotations when resolving hints
    Fix attribute hint lookup in Segment: previously code used self.__annotations__.get(...) which can be missing or misleading on instances. Use getattr(type(self), '__annotations__', {}) to reliably read class-level annotations and avoid incorrect lookups or AttributeError during attribute setting.
    [abstract.py]
2026-03-17 Refactor notification sending and target selection
    Extract target resolution and per-user send logic; add _get_targets to return either all users or the current user plus supervisors, and _send_to_user to build payload and POST to Pushover. send_notification now iterates over targets, skips when no targets configured, and emits clearer messages and errors that include the target name.
2026-03-19 Add user CLI; refactor habituation trials/stages
    Add a new 'user' CLI group with create/edit/inspect/list/remove commands to manage notification users via notificationmanager. Refactor lampyr.behaviors.bandit: adjust typing imports, rename/merge tr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
2026-03-19 Refactor HabituationTrial and remove Bandit code
    Streamline habituation behavior and remove the Bandit task/trial implementations. Changes include: shorten default ITI (iti1_dur 5->1), replace ranged reward consumption period with a fixed period, fix inconsistent attribute usage (use self.iti1_dur), remove trialstart registration and intermediate reward_delay, and simplify consumption/ no-lick polling logic. Deleted large BanditTrial/BanditTask implementations and updated RewardedHabituationTask to use the new HabituationTrial parameters. Also adjusted HabituationStage session params (serial_abstention_limit 15->10, reward_limit 150->200) and moved the stage class definition. These edits sim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
2026-03-20 Add Textual TUI (lampyr go) and numpad
    Introduce a full Textual-based touchscreen TUI and wire it into the CLI via a new `lampyr go` command. Adds a multi-screen UI (Main, Run, BehaviorSelect, Calibration) plus a NumpadModal and TUIInputBridge to route blocking input() calls from worker threads to the UI. Implements thread abort helper to raise KeyboardInterrupt in worker threads and improves run-time abort handling by setting a `_user_aborted` flag on Lampyr and including it in stopcodes. LampyrApp now injects the bridge as Lampyr's input function and provides `set_output()` to route manager output per-screen; it also auto-checks/pushes calibration screens. Replace previous placeholder UI c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
    [abstract.py]
2026-03-20 Update env scripts and add project dependencies
    Add an env update step to lampyr_update.bat to refresh the mx_hardware conda environment from mx_hardware.yaml. Add click, pip and art to the conda environment file (mx_hardware.yaml). Expand pyproje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
    [mx_hardware.yaml]
2026-03-20 Update installer scripts, env, and package data
    Make installer and environment changes: silence batch output (@echo off), ensure conda env is updated, and install the art package via the update script. Install Lampyr from the GitHub repo with --no-deps to avoid re-installing environment-managed dependencies. Move art out of the conda env YAML and add git as an explicit dependency in mx_hardware.yaml. Add setuptools package-data for the lampyr package to include .tcss and .css assets so they are packaged with the project.
    [mx_hardware.yaml]
2026-03-20 Add calibration confirm UI; touch bridge fix
    UI: Add a CalibrationConfirmScreen and related buttons/styles, plus a QUIT button and a return button for calibration. Update screen-push logic so an explicit confirm screen is shown before starting calibration and avoid duplicate pushes; add run-done success/error classes.
    Touch bridge: Set DefWindowProcW signature, make overlay window permanently WS_EX_TRANSPARENT (remove temporary style toggling) and include WS_EX_TRANSPARENT when creating the window; ensure SendInput behavior unchanged. Also call sys.exit(0) after running the app.
    Hardware: RigManager.calibrate now remembers previous connection state and disconnects if it opened the connecti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
2026-03-20 Forward mouse clicks and wheel through overlay
    Add support to forward real mouse button and wheel events through the touch overlay. New WM_ and MOUSEEVENTF constants were introduced, plus inject and inject_wheel helpers that briefly set the overlay window to WS_EX_TRANSPARENT, call SendInput, then restore the style. Window proc now intercepts WM_LBUTTON*/WM_RBUTTON*/WM_MOUSEWHEEL and synthesizes corresponding mouse input; an injecting flag prevents re-entrancy. Also removed the overlay's permanent WS_EX_TRANSPARENT style so events are only passed through when intentionally injected.
2026-03-20 Shorten segment slugs; enable wrap; adjust padding
    Add a TUI-only helper to compress long [segment_name] bracket content into an uppercase+digits-only form (applies to the second bracketed segment encountered) for more compact log display. Use this helper when writing to the RichLog, enable wrap on the RichLog widget, and tweak RunScreen padding from 1 2 to 1 1. Also import re as _re for the helper. These changes make run output more readable in the textual TUI without altering underlying logs.
2026-03-20 Don't push calibration during active run
    Add a session_running check in LampyrApp to detect if a RunScreen is present on the screen stack and prevent pushing CalibrationConfirmScreen while a run session is active. This avoids interrupting or overlapping an ongoing run when calibration expires.
2026-03-21 Add Bandit task/trial and merit toggle
    Introduce a Bandit training system: add BanditTrial and BanditTask dataclasses implementing pretrial hold, wheel-response detection, probabilistic rewards, merit/reward/demerit accounting, rescue tri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
2026-03-21 Restrict BanditTrial search to subdata children
    Replace a global session.search for 'BanditTrial' with an explicit loop over self.subdata, calling session.search(root=child_id, slug='BanditTrial', type='Trial') and extending a local trials list. This limits trial collection to the current subdata's children (avoiding cross-subdata aggregation) and initializes the trials list before extending it.
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2026-03-22 Refactor calib_disp to accept persistent initial weight
    Add an optional initial_value parameter to calib_disp so the initial weight prompt can be skipped for subsequent calibration runs. Increase dispense loop from 200 to 400 iterations and update dvol calculation to divide by 400. calib_disp now returns a tuple (dvol, new_value) and callers pass along next_initial to avoid repeated input prompts during multi-step calibration and final test.
2026-03-22 Clamp wheel thresholds to [5,40] range
    After adjusting left/right thresholds in AltWheelStage, clamp both aw['left_threshold'] and aw['right_threshold'] to the inclusive range 5–40. This prevents thresholds from becoming too small or excessively large after applying the correction_rate, keeping wheel difficulty values within safe bounds.
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2026-04-02 Lower bandit threshold; add backups; improve calibration
    Decrease BanditParadigm.hab_merit_threshold from 150 to 140. Add datamanager._backupmice() calls in Lampyr to back up mice data before creating a session and after saving the mouse. Improve RigManager calibration flow to treat an entered 0.0 as a restart signal (calib_disp returns None), skip the current calibration cycle when zero is entered, and retry the overall calibration loop until a valid measurement and regression are obtained. These changes prevent accidental zero-weight acceptance and ensure mice data are backed up around session runs.
2026-04-03 Altwheel: use adjustment_score for thresholds
    Replace separate left/right threshold state with a single adjustment_score for AltWheel shaping. Correction and return phases now modify/decay adjustment_score (bounded by new max_adjustment) and effective left/right thresholds are computed as N ± score clamped to [5,40]. Added max_adjustment default and logging updates, and a migration routine to convert existing left/right thresholds into adjustment_score (score = right_threshold - threshold_normal). This simplifies threshold updates and centralizes adjustment logic.
2026-04-06 Add paradigm STAGES and CLI stage handling
    Introduce a STAGES class variable on Paradigm (default empty) and define STAGES for BanditParadigm to enumerate valid training stages. Update the click CLI to allow setting a mouse's paradigm stage when no paradigm name is provided and to validate supplied stages (both when setting stage for current paradigm and when assigning a paradigm), persisting changes via mousemanager.save(). Remove the now-unused _store_params method and its call from BanditParadigm.execute since parameter storage is no longer performed.
2026-04-06 Pause return if bias; add normalization counter
    During the AltWheelStage 'return' phase, stop blindly moving the adjustment_score toward zero when a prevailing bias (sb) exists. Returns now occur only if the current bias is below p['equalize_threshold'] or the adjustment is against the prevailing bias; otherwise the return is paused and a notice is logged. When score reaches 0, require a consecutive_normalized streak (tracked in aw['consecutive_normalized']) of p['equalize_consecutive'] steps with low bias before marking the phase 'complete' (reset the counter if bias is present). Also initialize 'consecutive_normalized' in the BanditParadigm defaults. Logging messages were updated to reflec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
2026-04-07 Add docstrings and documentation to core modules
    Add comprehensive docstrings and explanatory comments across core modules (actions, analysis.*, behaviors/bandit, and config). Documents function/class purposes, parameters, return values, and error conditions (e.g. trace_extractor_factory, MultiSessionDataset, dynamic_trace_extraction, TimeTranslator, ltdataset decorator, parquet helpers, SessionInterpolatedTraceExtractor marked deprecated, Bandit paradigm/trials/stages, and Config/ConfigFile methods). Small behavioral clarifications were added (e.g. clear_files deletes dataset files and resets index). These changes improve code readability, IDE help, and support for automated documentation g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
    [abstract.py]
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2026-04-15 Enable merit counting; improve json loader
    Set HabituationTrial.count_merits to True to enable counting of merits by default. Removed an explicit self.finish() call after the habituation wait so the trial no longer finishes at that point. In AltWheelStage1, the direct call to applyadjustmentvalue(adj_val) was removed while adjustmentvalue is still recorded in global_paradigm_data (adjustment application likely handled elsewhere).
    Updated loadjson to wrap file reading in a try/except: it now prints the filepath on error and re-raises the exception to aid debugging of JSON load failures.
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2026-04-16 Add logging, fixes to bandit task and CLI
    Add informational logging across Bandit behaviors (reward dispensed/no-lick wait, pretrial/trial start, reward outcomes, block/target switches, rescue attempts, adjustment values, delays, and consecutive-good-session counts). Change some debug logs to info/notice for visibility and format sidebias notice. Prevent KeyError when reading reports by using .get for 'rewarded' and 'best_response'. In CLI, use paradigm.stagelist and stage.slug for valid stage checks and update mouse properties access to use paradigm slug. Add progression check notices around define_progression in paradigm segment. Miscellaneous minor formatting and control-flow tweaks.
2026-04-16 Use log_info and add diagnostic logs
    Replace many log_notice calls with log_info and add additional informational logging across Bandit behaviors to give clearer runtime diagnostics (session quality, adjustment values, delay changes, and consecutive-good counters). Refactor side-bias handling in AltWheel stages by introducing sign/signdiff helpers and bias labeling, and adjust logic for initializing/updating adjustment values. Increase merit threshold for delay progression from 140 to 150. Add progression and stage-change logging in Paradigm to report current stage and upcoming stage transitions and a debug log when advancing stages.
2026-04-17 Fix bandit behavior logic, logging, and formatting
    Several bug fixes and cleanups in bandit behaviors: use .get on rewardprobs_perc to avoid KeyError; fix log message parentheses and wrap long log strings; use >=150 for merit/participation thresholds; normalize side-bias labeling (Leftward/Rightward/Neutral) and tighten sign/signdiff helpers; clamp adjustment value to [-40, 40]; remove initial 0 from delay progression; minor whitespace/indentation and formatting adjustments (including rescue_trial instantiation). These changes improve robustness and clarity of runtime logs and bias/adjustment handling.
2026-04-17 Refine consecutive_good_sessions logic
    Update AltWheelStage1 adjustment logic to better track consecutive good sessions. When adj_val is 0, do not always assign a new adjustment: if side_bias is zero increment consecutive_good_sessions, otherwise set adj_val and reset the counter. Also increment consecutive_good_sessions when an adjustment is detected to have overshot the bias (signdiff case). This prevents unnecessary adjustments and more accurately records stable/good sessions.
2026-04-21 Extend rig calibration expiry to 36 hours
    Increase the rig calibration validity window from 12 hours (43200s) to 36 hours (129600s). Updated the expiry checks in lampyr/actions.py and lampyr/interfaces/textual_tui/app.py so CLI and TUI use the same 36-hour threshold to avoid premature calibration expiration.
2026-04-22 Add --recent filter to mouse list
    Expose a -recent/--recent flag on the mouse list CLI to only show mice run in the last 24 hours. The mouse_list handler now computes time_since_last from the last history entry and skips rows older than 86400 seconds when recent_only is set. Also removed an unused typing.ClassVar import from lampyr/segments/paradigm.py as a small cleanup.
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2026-04-24 Add session retrieval and mouse retire features
    Introduce a lightweight session-finding utility and mouse retirement flow. Added lampyr/analysis/retreival.py with find_sessions() to query mouse session history without loading full sessions. Record sessionid into session history entries when saving sessions. Expose mouse retirement in the CLI (mouse retire, and -all flag on mouse list) and persist retirement state on Mouse objects (primatives: retired field; MouseManager: retire and deretire). MultiSessionDataset gained an optional non-persistent mode (persistent flag) that prevents saving/loading when disabled and requires fp when persistent. Removed an obsolete visualize/session.py script.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
2026-04-24 Remove session retrieval; add history rebuild
    Delete the lampyr/analysis/retreival.py module (session-finding utilities removed). Update DataHandler: import pathlib.Path, drop "serial_abstention" from stored session summary fields, and add _mouse_session_list_from_files() plus reconstruct_all_mouse_history_from_files() to rebuild mouse.history from on-disk session files (prints progress, skips UNKNOWN_MOUSE, and tolerates individual session parse failures). Small cleanup in primatives.py (removed stray blank line). These changes provide a file-driven way to reconstruct mouse histories from existing .lampyr.json session files.
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2026-04-27 Support baseline subtraction in longtidy extraction
    Add baseline handling to longtidy_multidynamictraceextraction: new parameters baseline_range, baseline_events and baseline_kwargs allow computing and subtracting baseline traces. If baseline_events is provided, a separate extraction is run for those events and per-segment baseline means (over baseline_range) are subtracted from the main signals; if baseline_events is None the baseline_range is forwarded to the primary extraction. Also fix exposures construction to handle custom_exposures dicts and tidy perprofilekwargs merging/formatting.
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2026-04-29 Use f-strings in paradigm logging
    Replace literal brace templates with f-strings in lampyr/segments/paradigm.py so stageid and newstage are interpolated correctly in log messages. Updates log_notice calls in the stage run/exception paths and log_debug in the progression helper; no functional logic changes aside from log formatting.
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2026-04-30 Notifications: add user active flag and global token
    Introduce per-user active/inactive state and move Pushover app token to a global setting. NotificationManager.add_user now tracks an "active" flag and supervisors are always active; set_user_active and set_app_token methods added. Recipient selection now only includes active users plus supervisors, and _send_to_user gained an urgent/emergency option with appropriate Pushover payload. CLI updated: create/edit no longer take per-user app token, and new commands user set-token, activate, deactivate, and ping were added; list shows supervisor/active/inactive tags. Textual TUI: RunScreen starts a 10-minute timer after a finished run to alert us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
2026-05-01 Increase rig calibration timeout to 60h
    Extend rig calibration expiry from 129600s (36h) to 216000s (60h). Update checks in RunScreen and LampyrApp so both the runtime validation and the preemptive screen expiration logic use the new 60-hour threshold to avoid premature calibration expiry.
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2026-05-19 Adjust Bandit session params and rescue logic
    Update lampyr/behaviors/bandit.py: increase several session duration limits from 60 to 90 and raise minimum duration from 20 to 60 where appropriate; rename/replace reward_limit with reward_amount_limit and set it to 1.0 in stages. Tweak rescue/trial-start logic: tighten rescue conditional spacing and add a notification when serial abstention reaches >= 20. Remove a now-redundant define_sessionparams override in AnyWheelStage and clean up minor whitespace.
2026-05-19 Relax side-bias threshold and update logs
    In AltWheelStage2 (lampyr/behaviors/bandit.py) widen the no-bias window from 0.10 to 0.15 when adj_val == 0 and session.merit >= 150. Replace the previous f-string log messages with clearer, non-variable strings: the success case now logs 'No/low bias and sufficient performance for good session' and the failure case logs 'Bias or low performance detected'. This change makes it slightly easier to count consecutive good sessions and improves log readability; no other logic was modified.
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2026-06-12 Increased minimum python version
    [mx_hardware.yaml]
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2026-06-25 Extend calibration timeout and add heartbeat
    Increase rig calibration expiry to 5 days (replace magic-second literals with (5*24*60*60)) in both actions and the Textual TUI, and unify the GUI check by renaming _check_calibration to _heartbeat. In the app, run the heartbeat every 20 minutes, and when no session is running attempt a datamanager.heartbeat_filetouch, reporting failures via a notification. Keeps existing guard logic to avoid pushing duplicate calibration screens.
2026-06-25 Added OpenCV dependency
    [mx_hardware.yaml]
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2026-06-30 Fixed duplicate frame issue in ArduCam Interface
    OpenCV MSMF backend regrabs last frame when frame is not available.
    [interfaces.py]
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2026-07-01 Replace deprecated OpenCV setLogLevel with env var
    Update OpenCV logging suppression to use OPENCV_LOG_LEVEL environment variable instead of the deprecated cv2.setLogLevel() method, which was removed in newer OpenCV versions. Also specify minimum OpenCV version 4.12 in dependencies.
    [mx_hardware.yaml]
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2026-07-01 Use threshold_RMS parameter in Arducam interface
    Fix CameraInterface_Arducam initialization to use the threshold_RMS parameter instead of hardcoding it to 2.0. This allows callers to customize the threshold value as intended.
    [interfaces.py]
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2026-07-14 Skip bad sessions; add trial-level laser mode
    Colony: add skip_bad_sessions flag and skipped_sessions list; make load_session catch failures and delegate to _handle_session_load_error which logs/skips sessions when configured (returns None) or re-raises otherwise. SessionQuery and related callers now tolerate None sessions (filtering them out and improving error message when load fails).
    Bandit: add pretrial_laser_enabled and emit laser_onset before pretrial when enabled. Add laser_trial_sequence_type ('response' or 'trial') and current_trial_number to support trial-indexed laser scheduling, include pretrial param in laser params, and increment current_trial_number per run. Add EXPeriment_L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
2026-07-29 Fixed timer conflict with laser and response tone
2026-08-03 Adding hardware files prior to pub
    [BOM_Hardware.xlsx, HudaHub_R0_3_1_bom.csv, HudaHub_R0_3_1_designators.csv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]
2026-08-12 Various part files
    [cameramount_part49.stl, encoderwheeladapter_part48.stl, mouseplatform_part47.stl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]
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2026-09-22 Fix for timer conflict in pretrial laser experiment
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
